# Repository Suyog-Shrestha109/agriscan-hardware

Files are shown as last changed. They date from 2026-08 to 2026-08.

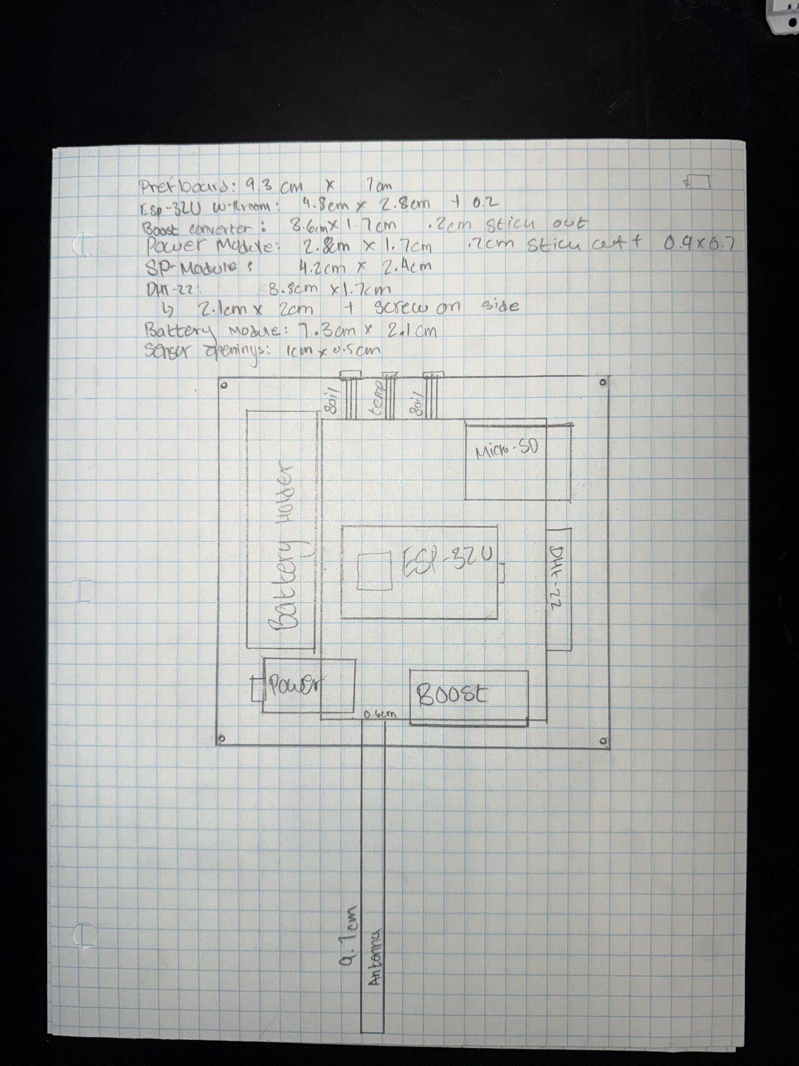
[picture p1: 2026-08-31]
hardware/hub-perfboard-layout-dimensioned.jpg

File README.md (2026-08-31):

# AgriScan — ESP32-to-ESP32 BLE Communication Layer

**Author:** Suyog Shrestha
**Project:** AgriScan (Unity Provisions) — WiFi-free soil moisture sensing for small farms
**Tracked in the project task system as:** "Work on the Bluetooth-like connection between ESP32s"
**Written:** January 22, 2026 — recovered from Slack `#agriscan-general`

The device-to-device communication layer for AgriScan was built in four stages in one session.
The product requirement driving this work: the system has to move sensor data between a Hub
and remote CropBands **without any internet connection**, because the farms it targets don't
have one.

## Progression

| File | Time | What it adds |
|---|---|---|
| `01_sender_basic.ino` | 17:54 | Advertises as `ESP32_SENDER`, custom service/characteristic UUIDs, notifies a ticking counter to prove the channel works |
| `02_receiver_basic.ino` | 17:56 | Scans, matches on device name, connects, reads once, subscribes to notifications, retries on failure |
| `03_sender_ntp_time.ino` | 18:33 | Real-time clock over WiFi via NTP, with graceful fallback to device uptime when WiFi is unavailable; streams timestamped payloads |
| `04_receiver_time_range.ino` | 18:37 | Converts RSSI to estimated distance via the log-distance path-loss model |

## The physics in stage 4

```
distance = 10 ^ ((txPower - rssi) / (10 * n))
```

`txPower` is the reference RSSI at one meter (−59 dBm default), `n` is the path-loss exponent
(2.2 here, tuned above the free-space value of 2.0 to account for obstruction). Signal strength
falls off logarithmically with distance, so inverting that relationship gives a distance estimate
from a value the radio already reports.

## Design decisions worth noting

- **Named-device matching rather than UUID-only scanning** — simpler pairing, at the cost of
  requiring a known device name.
- **NTP with an uptime fallback** — the device must keep producing usable timestamps when the
  network is unavailable, which is the normal case in the field. Rather than blocking on WiFi,
  it degrades to monotonic uptime.
- **8-second WiFi timeout, 20 × 200ms NTP retry** — bounded so the device always reaches its
  BLE advertising state.
- **Notification-based rather than polling** — the receiver subscribes instead of repeatedly
  reading, which matters for battery life on a field-deployed sensor.

## Known limitations

- WiFi credentials are hardcoded placeholders; provisioning was not yet built.
- The path-loss exponent `n` is estimated, not calibrated against measured distances.
- Distance estimation from RSSI is inherently noisy and needs filtering before it drives anything.

## Where this fits

CropBands and the Hub both run the ESP32-WROOM-32U, so this device-to-device work applies directly to both ends — one chip, one radio stack, one packet format.

The production link uses ESP-NOW rather than BLE, which is the right call for the deployment:
ESP-NOW is connectionless, lower latency, and needs no pairing state that has to survive a
deep-sleep cycle. The BLE work here established the device discovery, connection, notification,
and RSSI-ranging patterns the ESP-NOW implementation builds on.

## Sensor integration

`src/05_sensor_integration.ino` — written ~April 2026

Reads the three sensor types on a node and prints them over serial:

| Sensor | Interface | Reads |
|---|---|---|
| DS18B20 | 1-Wire, 4.7k pull-up on DQ | Soil temperature |
| DHT22 (AM2302) | Single-wire digital | Air temperature, humidity |
| 2 x capacitive probe | Analog | Soil moisture, raw ADC |

Two decisions in here:

- **Capacitive probes rather than resistive.** Resistive metal-to-soil probes corrode and drift once they have been sitting in wet soil, which rules them out for a sensor meant to stay buried in a field.
- **Raw ADC values are printed, not converted percentages.** Calibration and the soil physics live on the Hub, so improving the moisture model never requires reflashing sensors already deployed.

---

**Source:** Slack `#agriscan-general`, 2026-01-22. Recovered verbatim; the only edit is restoring
`pool.ntp.org` in stage 3, which Slack had auto-linked.

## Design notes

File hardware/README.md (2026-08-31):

# Hardware

Design documents for the AgriScan hub.

| File | What it is |
|---|---|
| `hub-perfboard-layout-dimensioned.jpg` | Hand-drawn component layout, 9.3 × 7 cm perfboard. Measured footprints, clearances, connector positions, mounting holes. The enclosure CAD was dimensioned from this. |
| `AgriScan Hub Prefboard.kicad_sch` | Hub schematic — KiCad source |
| `AgriScan Hub Prefboard.kicad_pro` | KiCad project file |
| `AgriScan Hub Prefboard.pdf` | Schematic, plotted for viewing |
| `bom.csv` | Bill of materials, generated from the schematic |

## Power chain

Voltaic 6V 2W panel → bq24074 DC jack → 18650 (1S DW01 protection) → MT3608 boost → 5V → ESP32.
No diode or clamp — the bq24074 handles reverse current and input limiting internally.

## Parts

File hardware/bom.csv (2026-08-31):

Reference | Qty | Value | DNP | Exclude from BOM | Exclude from Board | Footprint | Datasheet
Capacitive1,Capacitive2 | 2 | Soil Moisture Sensor
J1 | 1 | Micro_SD_Card |  |  |  |  | https://www.we-online.com/components/products/datasheet/693072010801.pdf
R1 | 1 | 4.7k
U1 | 1 | DS18B20 |  |  |  | Package_TO_SOT_THT:TO-92_Inline | http://datasheets.maximintegrated.com/en/ds/DS18B20.pdf
U2 | 1 | ESP32-WROOM-32U |  |  |  | RF_Module:ESP32-WROOM-32U | https://www.espressif.com/sites/default/files/documentation/esp32-wroom-32d_esp32-wroom-32u_datasheet_en.pdf
U3 | 1 | AM2302 |  |  |  | Sensor:ASAIR_AM2302_P2.54mm_Vertical | http://akizukidenshi.com/download/ds/aosong/AM2302.pdf

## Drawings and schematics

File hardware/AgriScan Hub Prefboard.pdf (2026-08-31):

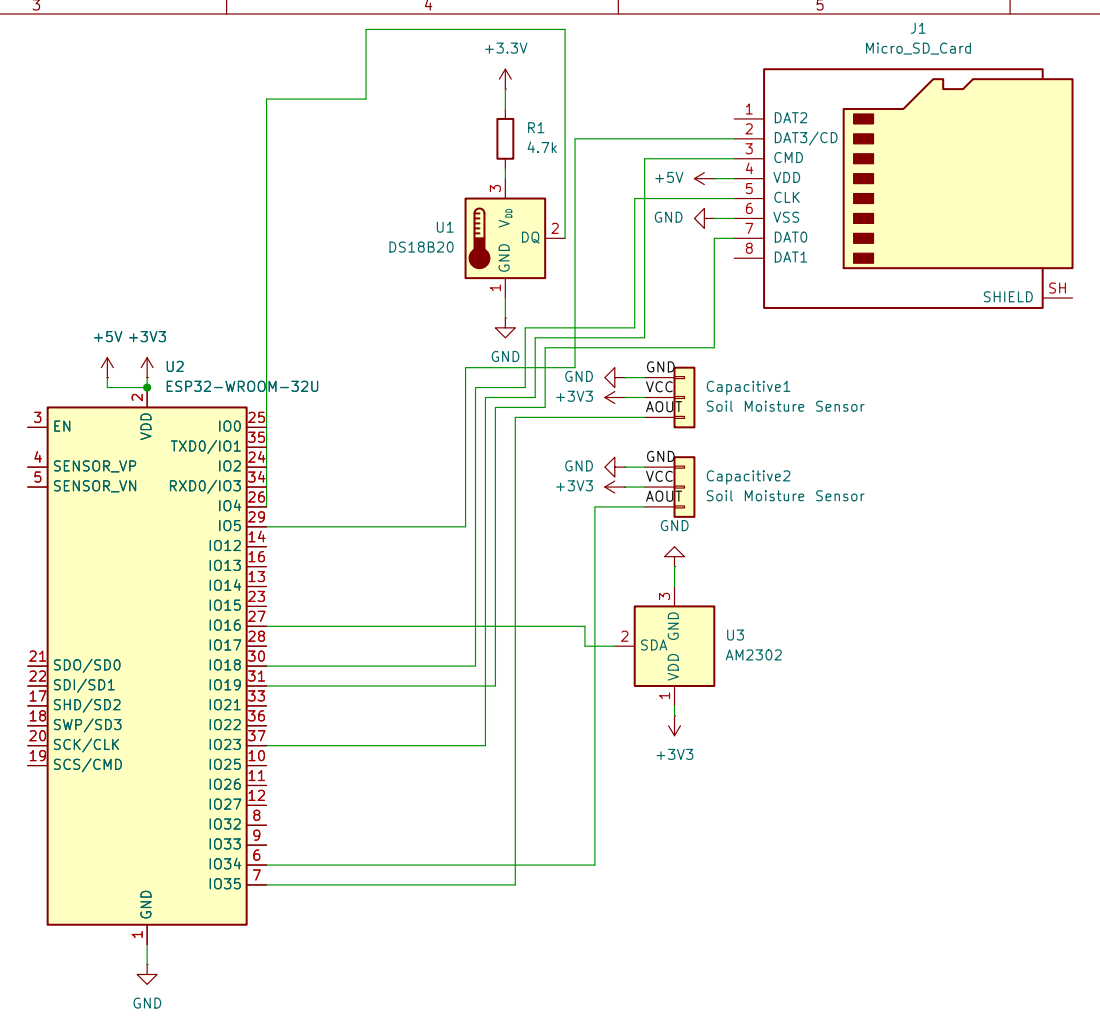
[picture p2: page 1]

GND
Soil Moisture Sensor VCC
AOUT AOUT GND

Sheet: /
File: AgriScan Hub Prefboard.kicad_sch
Title:

Size: A4 | Rev:
KiCad E.D.A. 10.0.0 | Id: 1/1

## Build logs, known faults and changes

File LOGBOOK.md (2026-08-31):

# AgriScan — Build Log

## 2026-08-31

Set up this repo. Recovered the BLE sketches from Slack — they had never been committed anywhere. Added the sensor integration sketch too.

Found the KiCad schematic from April and got it into version control: source, plotted PDF, and a generated BOM. Ran Annotate first — the second soil sensor header was still sitting at `Capacitive?` and showing up wrong in the BOM. Also added the hand-dimensioned perfboard layout drawing.

Design note: CropBands now run the same ESP32-WROOM-32U as the Hub, not the C3. One chip, one radio stack, one packet format on both ends.

Next up:
- Reflow the intermittent OUT/GND joint to the MT3608, flex-test under continuity
- Set the boost trimpot to 5.00V with output floating, before reconnecting the ESP32
- Confirm the 3V3 pin reads 3.3V after the 9V incident
- Push the firmware fixes (shared hub_config.h + static_assert on packet size) — waiting on repo access

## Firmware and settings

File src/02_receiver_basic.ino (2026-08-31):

// AgriScan — ESP32-to-ESP32 BLE, Stage 2: basic receiver
// Author: Suyog Shrestha
// Posted: 2026-01-22 17:56:54 EST, Slack #agriscan-general
// Scans for ESP32_SENDER, connects, reads once, subscribes to notifications.

#include <BLEDevice.h>
#include <BLEUtils.h>
#include <BLEScan.h>
#include <BLEAdvertisedDevice.h>

static const char* TARGET_NAME = "ESP32_SENDER";

// Must match sender
static BLEUUID SERVICE_UUID("12345678-1234-1234-1234-1234567890ab");
static BLEUUID CHAR_UUID ("abcdefab-1234-1234-1234-abcdefabcdef");

static BLEAdvertisedDevice* targetDevice = nullptr;
static bool doConnect = false;
static bool connected = false;

static BLERemoteCharacteristic* pRemoteCharacteristic = nullptr;

static void notifyCallback(
BLERemoteCharacteristic* pBLERemoteCharacteristic,
uint8_t* pData,
size_t length,
bool isNotify
) {
Serial.print("Notify: ");
for (size_t i = 0; i < length; i++) Serial.print((char)pData[i]);
Serial.println();
}

class MyAdvertisedDeviceCallbacks : public BLEAdvertisedDeviceCallbacks {
void onResult(BLEAdvertisedDevice advertisedDevice) override {
if (advertisedDevice.haveName() && advertisedDevice.getName() == TARGET_NAME) {
Serial.println("Found ESP32_SENDER!");
Serial.print("Address: ");
Serial.println(advertisedDevice.getAddress().toString().c_str());
Serial.print("RSSI: ");
Serial.println(advertisedDevice.getRSSI());

targetDevice = new BLEAdvertisedDevice(advertisedDevice);
doConnect = true;

BLEDevice::getScan()->stop();
}
}
};

bool connectToServer() {
Serial.println("Connecting to sender...");

BLEClient* pClient = BLEDevice::createClient();
if (!pClient->connect(targetDevice)) {
Serial.println("Connect failed.");
return false;
}
Serial.println("Connected!");

BLERemoteService* pRemoteService = pClient->getService(SERVICE_UUID);
if (pRemoteService == nullptr) {
Serial.println("Service not found.");
pClient->disconnect();
return false;
}

pRemoteCharacteristic = pRemoteService->getCharacteristic(CHAR_UUID);
if (pRemoteCharacteristic == nullptr) {
Serial.println("Characteristic not found.");
pClient->disconnect();
return false;
}

// Read once
if (pRemoteCharacteristic->canRead()) {
String val = pRemoteCharacteristic->readValue();
Serial.print("Initial read: ");
Serial.println(val);
}

// Subscribe to notifications
if (pRemoteCharacteristic->canNotify()) {
pRemoteCharacteristic->registerForNotify(notifyCallback);
Serial.println("Registered for notifications.");
} else {
Serial.println("Characteristic cannot notify.");
}

return true;
}

void setup() {
Serial.begin(115200);
Serial.println("Starting BLE Receiver...");

BLEDevice::init("ESP32_RECEIVER");

BLEScan* pScan = BLEDevice::getScan();
pScan->setAdvertisedDeviceCallbacks(new MyAdvertisedDeviceCallbacks());
pScan->setActiveScan(true);
pScan->setInterval(1349);
pScan->setWindow(449);

Serial.println("Scanning for ESP32_SENDER...");
pScan->start(0, false); // 0 = scan forever until stopped
}

void loop() {
if (doConnect && !connected) {
connected = connectToServer();
doConnect = false;

if (!connected) {
Serial.println("Retry scan in 2 seconds...");
delay(2000);
BLEDevice::getScan()->start(0, false);
}
}

delay(200);
}

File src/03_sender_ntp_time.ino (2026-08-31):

// AgriScan — ESP32-to-ESP32 BLE, Stage 3: sender with real-time clock
// Author: Suyog Shrestha
// Posted: 2026-01-22 18:33:48 EST, Slack #agriscan-general
// Pulls time over WiFi via NTP, with graceful fallback to device uptime
// if WiFi is unavailable. Streams timestamped payloads over BLE.

#include <BLEDevice.h>
#include <BLEServer.h>
#include <BLEUtils.h>
#include <BLE2902.h>

#include <WiFi.h>
#include <time.h>

// ====== SET THESE FOR REAL CLOCK TIME (NTP) ======
const char* WIFI_SSID = "YOUR_WIFI_SSID";
const char* WIFI_PASS = "YOUR_WIFI_PASSWORD";
const char* NTP_SERVER = "pool.ntp.org";

// New York offset (EST). Change if needed.
const long GMT_OFFSET_SEC = -5 * 3600;
const int DST_OFFSET_SEC = 0; // set 3600 if you want DST manually

// ===== BLE IDs (must match receiver) =====
static const char* DEVICE_NAME = "ESP32_SENDER";
static BLEUUID SERVICE_UUID("12345678-1234-1234-1234-1234567890ab");
static BLEUUID CHAR_UUID ("abcdefab-1234-1234-1234-abcdefabcdef");

BLECharacteristic* pCharacteristic = nullptr;
bool deviceConnected = false;

class MyServerCallbacks : public BLEServerCallbacks {
void onConnect(BLEServer* pServer) override {
deviceConnected = true;
Serial.println("Client connected!");
}
void onDisconnect(BLEServer* pServer) override {
deviceConnected = false;
Serial.println("Client disconnected. Restarting advertising...");
BLEDevice::startAdvertising();
}
};

void setupTimeViaNTP() {
WiFi.mode(WIFI_STA);
WiFi.begin(WIFI_SSID, WIFI_PASS);

Serial.print("WiFi connecting");
unsigned long start = millis();
while (WiFi.status() != WL_CONNECTED && millis() - start < 8000) {
delay(250);
Serial.print(".");
}
Serial.println();

if (WiFi.status() == WL_CONNECTED) {
Serial.print("WiFi OK: ");
Serial.println(WiFi.localIP());

configTime(GMT_OFFSET_SEC, DST_OFFSET_SEC, NTP_SERVER);

// wait briefly for NTP to sync
for (int i = 0; i < 20; i++) {
struct tm t;
if (getLocalTime(&t, 50)) {
Serial.println("Time synced via NTP.");
return;
}
delay(200);
}
Serial.println("NTP not ready yet; will fallback to uptime until it is.");
} else {
Serial.println("WiFi failed; will use uptime time.");
}
}

String getTimeString() {
struct tm timeinfo;
if (getLocalTime(&timeinfo, 50)) {
char buf[32];
strftime(buf, sizeof(buf), "%Y-%m-%d %H:%M:%S", &timeinfo);
return String(buf);
}
return String("uptime_ms=") + String(millis());
}

void setup() {
Serial.begin(115200);
delay(300);

Serial.println("Starting BLE Sender (live time only)...");
setupTimeViaNTP();

BLEDevice::init(DEVICE_NAME);

BLEServer* pServer = BLEDevice::createServer();
pServer->setCallbacks(new MyServerCallbacks());

BLEService* pService = pServer->createService(SERVICE_UUID);

pCharacteristic = pService->createCharacteristic(
CHAR_UUID,
BLECharacteristic::PROPERTY_READ |
BLECharacteristic::PROPERTY_NOTIFY
);
pCharacteristic->addDescriptor(new BLE2902());
pCharacteristic->setValue("time=booting...");

pService->start();

BLEAdvertising* pAdvertising = BLEDevice::getAdvertising();
pAdvertising->addServiceUUID(SERVICE_UUID);
pAdvertising->setScanResponse(true);
pAdvertising->start();

Serial.println("Advertising as ESP32_SENDER...");
}

void loop() {
String payload = "time=" + getTimeString();

pCharacteristic->setValue(payload.c_str());

if (deviceConnected) {
pCharacteristic->notify();
Serial.print("Notified: ");
} else {
Serial.print("Set (no client): ");
}
Serial.println(payload);

delay(1000);
}

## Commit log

2026-08-31 Rename AgriScan Hub Prefboard.csv to bom.csv
    [bom.csv]
2026-08-31 Document sensor integration sketch (05)
